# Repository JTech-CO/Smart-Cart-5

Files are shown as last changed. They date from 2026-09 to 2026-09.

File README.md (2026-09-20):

# Smart-Cart-5

[한국어](README-KR.md) · [Assembly viewer](<https://jtech-co.github.io/Smart-Cart-5/>) · [Wiring viewer](<https://jtech-co.github.io/Smart-Cart-5/wiring.html>)

A build-oriented integration model based on a purchased 900 × 600 mm folding platform cart, the supplied V8 component specification, and the original Motor-Bracket/SCMB geometry. Two upright lead-acid batteries sit below the deck, left and right. Rear MY1016Z drives use identical, rigidly rotated SCMB brackets; the controller is a Raspberry Pi 4B 8GB. A handle-mounted NC emergency stop and a separate reset button are included.

**Prototype integration only: dimensional measurement, structural verification and electrical energization remain on hold.** The supplied specification contains unmeasured components. Proposed dimensions and added electrical modules are not presented as purchased-product specifications. The model is not a certified safety system or a production-release drawing.

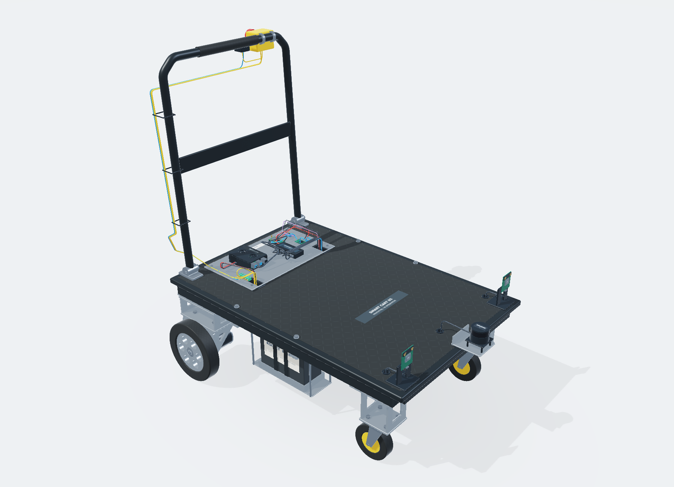
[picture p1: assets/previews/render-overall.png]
Assembly


## Run

Run `start-local.bat` with Python 3 installed, or `./start-local.sh`. Alternatively:

```sh
python -m http.server 8000 --bind 127.0.0.1
```

Serve the repository root. Direct `file://` loading is not supported. The browser runtime is static, with no CDN, account, API key or npm build. The root is suitable for GitHub Pages; no repository has been published by this package.

Drag to orbit, right-drag/Shift-drag to pan, wheel to zoom, double-click to focus. Underside orbit automatically suppresses the ground. WebGL 2 is the primary renderer; a same-mesh depth-buffered Canvas CPU fallback is included for environments without WebGL 2. It is slower and has simplified shading.

## Deliverables

- `cad/Smart-Cart-5.step`: true mm-unit CAD solids, not triangles.
- `cad/Smart-Cart-5.FCStd`: D5-only colored Part::Feature snapshot; no native PartDesign history.
- `cad/Load-Smart-Cart-5.FCMacro`: import the matching BREP files in FreeCAD and fit the view.
- `data/assembly.json`, `geometry.bin`, `connections.csv`: one source for the viewer and 50 routed electrical connections/harnesses.
- `tools/build_release.py`: regenerate geometry, inspect registered cable/solid intersections, and export matching artifacts.

`pip install -r requirements-cad.txt` is needed only for CAD regeneration. Source layout coordinates must be reviewed alongside changed parameters; this is not an automatic routing/structural-optimization system. See the [Korean build guide](docs/BUILD-GUIDE-KR.md) and [QA scope](docs/QA-KR.md).

Native FreeCAD/SolidWorks GUI opening and physical fabrication were not executed. BREP, FCStd payload order and STEP round-trips were checked separately. Browser UI/fallback checks and standalone EGL production-shader renders are distinguished in the QA report.

Original hardware names remain the property of their owners. See [source notices](docs/EVIDENCE-KR.md); this package does not assign a new license to the referenced Motor-Bracket repository.

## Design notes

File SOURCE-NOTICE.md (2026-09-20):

# Source and asset notice

Smart-Cart-5 is a user-requested prototype integration package based on the supplied V8 parts document and JTech-CO's Smart-Cart-4 and Motor-Bracket repositories. See `docs/EVIDENCE-KR.md` for exact scope and source identifiers. The original Motor-Bracket geometry is retained and its engineering-review status remains in effect. This package does not assign a new blanket license to upstream material.

Product names and generated component labels identify referenced hardware; they do not imply manufacturer approval. All preview images are renders of the generated geometry, not photographs of an assembled cart. No proprietary supplier CAD or unavailable product photographs are claimed. The user's original DOCX and font files are not redistributed.

The web runtime does not depend on an external CDN, analytics endpoint, account, API key or live device connection. CAD generation/test dependencies are not required to open the static web viewer through a local HTTP server.

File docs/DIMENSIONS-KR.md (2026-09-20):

# 치수와 근거 등급

단위 mm. 좌표는 +X 전방, +Y 차체 좌측, +Z 위쪽, 바닥 Z=0이다. A=V8 공식자료, B=계열 참고, M=실측 필요, D=이번 배치 제안이다. 같은 부품이라도 PCB 외곽은 A이고 케이스·커넥터·장착 위치는 D/M일 수 있다.

| 항목 | 적용값 | 근거와 한계 |
|---|---|---|
| 카트 상판 | 900×600 | V8 p9-10 구매 옵션 A |
| 상판 상면 높이 / 두께 | 310 / 18 | D/M. 특대형 실측값 아님 |
| 기존 프레임 | 30×30, 벽 2 | D/M. 실제 단면·용접·볼트 접근 미확정 |
| 전륜 | Ø110 TPR | V8 구매 옵션. 폭32·트레일28·장착면142는 D/M |
| 후륜 | Ø200×40, 허브30 | D/M. V8 확정은 Ø17 보어 옵션뿐 |
| 후륜 축 중심 | X=-335, Y=±319 휠 중심, Z=100 | D 통합 배치 |
| 모터 | 길이170, 축Ø17×44, 몸통Ø72 | V8 p12. 기어박스 윤곽·축 어깨·케이블 출구는 M |
| 충돌 자료 | 원본 브라켓 참고 몸통Ø102 | Ø72와 미해결. 어느 쪽도 실측 확정 취급하지 않음 |
| SCMB 단품 | 148×88×130, 주요 판8 | 원본 형상 구성 유지. 새 카트 체결·하중 검증 없음 |
| 모터 홀 X/Z | (-24.7,42.3), (2.1,55), (54.7,2.1), (41.8,-24.6) | 원본 국부 좌표, 거울상으로 바꾸지 않음 |
| 배터리 | 181×77×167, 2개 | V8 p7 A/B. 약5.5kg/개, 단자 위치·입고 변형 M |
| 배터리 배치 | X=-40, Y=±185, 바닥Z84 | D. 두 개 모두 세운 자세 |
| 트레이 최저점 | 약79 | D. 전체 차량 최소 지상고와 같지 않음 |
| 배터리 가로 보강대 | 30×590×10, 2개 | D/M. 원래 차체 실측과 하중 검증 필수 |
| Pi PCB | 85×56 | V8 p24 A |
| Pi + RBP-002 케이스 | 100×75×35 공간예약 | V8 D/M. 실제 케이스·팬·포트 외곽 미확정 |
| BU04 PCB | 46×52, 2개 | V8 A. 지지대·방향·최대높이 M/D |
| BU03 PCB | 35.56×55, 1개 | V8 A. 사용자 소지 외장품, 카트에 붙이지 않음 |
| RPLIDAR C1 | 55.6×55.6×41.3 | V8 p13 A. 홀43×43, M2.5 체결깊이≤4 |
| C1 스캔 높이 | 바닥 기준 367.8 | D 배치 + V8 센서 기준면29.8. 적재물로 후방 가림 가능 |
| ESP32 | PCB54.4×27.9 참고 | V8 B/M. 48.26 길이의 다른 공식 리비전과 혼동 금지 |
| BTS7960 | 보수 공간52×52×43, 2개 | V8 D/B/M. 실제 PCB·방열판·단자 순서 M |
| INA226 | PCB27×20 참고 | V8 B/M. 전류 패드 OPEN, VBUS 접근 핀 M |
| 손잡이 | 상판 위670, 튜브Ø25 | D/M. 작은 카트 이미지의 값을 특대형 확정값으로 전용하지 않음 |
| 12AWG / 18AWG 외경 | 4.4 / 2.6 | V8 범위 내 임시값. 공급품 실제 외경과 허용 굴곡 우선 |

DC/DC, 접촉기, 분배 단자, 퓨즈 하우징, 비상정지 박스, RESET, USB 허브, 레벨 인터페이스, 보강대, 제어 커버는 추가 설계품 또는 공간예약이다. 외형이 보인다는 이유로 특정 판매제품과 일치한다고 해석하면 안 된다.

V8에서 별도 제품사진이나 정확한 도면이 제공되지 않은 부품의 IC·방열판·팬·단자 디테일은 시각 참고 형상이다. PCB 배선 패턴이나 케이스 내부까지 실물을 복제한 것은 아니다. 원본 18kg 시나리오는 이번 카트의 검증된 총중량·적재하중이 아니며 승차를 허용하지 않는다.

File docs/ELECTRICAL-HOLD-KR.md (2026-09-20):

# 통전 보류 조건

서비스 커넥터는 OPEN이다. 렌더링과 솔리드 간섭 검사는 전기 안전 검증이 아니다. 아래 사항이 해결되기 전 모터 구동 전원을 연결하지 않는다. 실제 위험 에너지는 두 납축전지에서 발생하므로 단순히 소프트웨어 PWM을 0으로 만드는 것으로 정비 격리를 대신하지 않는다.

## 공급·보호 소자 선정

V8에는 퓨즈, 접촉기, DC/DC, 비상정지 접점과 USB 허브의 확정 모델이 없다. 본 패키지는 위치와 배선 공간을 추가했을 뿐 재고·구매 가능성과 정격 적합성을 확정한 BOM이 아니다. 배터리 측 두 퓨즈와 좌우 모터·보조전원·코일·계측 분기 퓨즈는 모두 TBD이다. 전선 허용전류, 단자·커넥터 정격, 모터 기동/구속 전류, 온도 및 DC 차단용량에 맞춰 선정해야 한다. USB나 보조 배선 규격을 모터 전류 경로에 적용하지 않는다.

V8의 BTS7960 표기 43A는 지속전류 보증치가 아니다. 구매 모듈의 입력 상한, 충전 조건에서의 배터리 전압, 감속 회생 및 배선 과도전압, 방열판 온도와 연속 운전 온도를 검증한다. 아직 선정되지 않은 TVS·회생 흡수·과전압 보호 소자가 동작한다고 가정하지 않는다. 차체를 귀환 전류 경로로 쓰지 않는다.

Pi4에는 조정된 별도 5.1V 공급이 필요하다. 공식 Pi4 전원은 5.1V 3A이며, 여기서 표시한 6A 이상 DC/DC 공간은 Pi·외부전원 USB 허브·보조부를 함께 고려한 설계 예산이지 선정된 부품 사양이 아니다. 실제 케이블 전압 강하, USB-C 연결 방식, 허브 역급전 방지, 총 센서 소비전류와 리플을 확인한다. V8의 UWB 보드 전원 권고를 모든 포트가 동시에 만족하는지 확인한다.

## 비상정지

E-stop의 NC 접점은 K1 앞의 퓨즈에서 공급받는 코일 회로에 직렬로 둔다. RESET 순간 NO와 K1 보조 NO를 병렬로 하는 자기유지 구성을 제안한다. E-stop 해제만으로 코일이 다시 유지되면 안 된다. 코일 단락·억제 소자·단선·접점 용착·제어기 부팅/리셋·PWM 기본 상태를 확인한다. 회로의 안전 성능 수준이나 정지 카테고리를 인증한 것은 아니다.

코일 억제 부품은 낙하시간에 영향을 주므로 실제 선정과 시험이 필요하다. 이 모델에는 최종 억제 소자가 선정·검증되어 있지 않다. 구동 전원 차단은 제동 장치가 아니다. 관성, 경사면 밀림, 정지거리, 잔류 전압을 실측하고 필요한 제동 방법을 별도로 결정한다.

이 버전의 Pi/DC/DC 분기는 K1 뒤에 있다. 비상정지 시 Pi도 강제 전원 차단된다. 읽기 전용 OS·데이터 보호 또는 별도 로직 전원 계통을 적용하기 전 저장장치의 안전한 종료가 보장되지 않는다. 모델에 없는 UPS나 유지 전원을 있다고 간주하지 않는다.

## 계측과 신호

INA226의 R010 경로는 두 모터의 합산 전류를 흘리는 경로에 넣지 않았다. V8의 ‘20A급 판매모듈 사례’는 모터 피크 적합성 검토가 필요하다고 표시되어 있다. VBUS 감시를 위한 저전류 분기만 제안했고, 구매 모듈에서 VBUS 핀에 접근 가능한지부터 확인해야 한다. 실제 전체 전류 측정은 허용 범위가 맞는 외부 션트·보호·캘리브레이션을 별도로 설계한다.

BTS7960, ESP32와 레벨 인터페이스의 실제 핀 순서·전압 문턱·기본 비활성 상태를 확인한다. CSV의 제어 하네스 항목은 묶음 케이블 경로이다. 개별 GPIO 핀번호까지 검증된 배선표가 아니다. 이 저장소는 로봇 주행 펌웨어나 제어 알고리즘을 구현하지 않는다.

## 충전·정비

2개의 12V 충전기는 외장품이다. 배터리와 직렬 링크를 안전하게 분리·절연한 상태에서 각각 충전하며, 충전기 출력 사이의 절연을 확인하지 않은 병행 연결은 제시하지 않는다. 실제 단자 압착, 러그 볼트, 피복 보호, 퓨즈 홀더 체결과 극성 표시를 확인한다. 최초 시험은 바퀴를 지면에서 띄우고 적절한 전류 제한·전압 계측 환경에서 수행하며, 장착 상태 하중·제동 시험과 분리한다.

출처: 첨부 V8 p3/5/17/19/22-26 및 Raspberry Pi 공식 전원 제품 페이지. https://www.raspberrypi.com/products/type-c-power-supply/

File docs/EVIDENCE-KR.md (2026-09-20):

# 근거와 설계 결정

기준일: 2026-09-21. 이 파일은 구매품의 실측 보고서가 아니라, 받은 자료에서 가져온 값과 이번 통합 모델의 제안을 구분하는 추적표이다.

## 1. 입력 자료

**사용자 제공 V8**: `AI_자율추종_캐리어_Astra_3D_CAD_부품규격서_V8_내용정리본.docx`. 문서의 A/B/M 구분과 품목 1~15 구성을 기준으로 했다. 원본 문서는 이 배포물에 재포함하지 않는다. 아래 페이지 번호는 제공 문서의 렌더된 30페이지 기준이다.

| V8 위치 | 모델에 사용한 근거 | 이번 모델에서 확정하지 않은 것 |
|---|---|---|
| p3~6, BU03/BU04 | PCB 35.56×55 / 46×52, BU04 2개 | 전체 높이, 안테나 방향과 금속 이격 성능, 커넥터/지지대 |
| p7~8, 배터리 | 181×77×167, 2개, 약5.5kg/개 | 입고 변형, 정확한 단자 좌표, 실물 총중량 |
| p9~10, 카트 | 특대형 구매 옵션 900×600, 110mm TPR | 상판 높이·두께, 프레임 단면·용접, 큰 카트의 손잡이·힌지 |
| p11~12, 모터 | MY1016Z 24V250W, 180rpm 옵션, 길이170, 축Ø17×44, V8 몸통Ø72 | 기어박스 외곽·귀 두께·축 어깨·허브 결합·축 허용하중 |
| p13~14, C1 | 55.6×55.6×41.3, 홀43×43, 기준면+29.8 스캔 높이 | 특정 적재 상태의 스캔 가림과 장애물 검출 성능 |
| p15~18, ESP32/드라이버 | ESP32 참고 외곽, BTS7960 보수 공간52×52×43 | 구매 리비전의 핀/단자 순서, 지속전류·방열 |
| p19~21, 충전기/터미널 | 충전기는 외장 사용 가능, 사용하는 단자만 모델링 | 충전기 절연·단자별 전류 정격. 소모품 상자는 탑재하지 않음 |
| p22~23, 케이블 | 12AWG 4~4.5 OD, 18AWG 2.3~2.9 OD 참고, 4×OD 임시 굴곡 기준 | 실제 공급 케이블의 외경·굴곡·단자 압착·허용전류 |
| p24~25, Pi | Pi 4B 8GB, PCB85×56, RBP-002 100×75×35 공간예약 | 실제 케이스 외곽·팬·포트·고정홀 |
| p26~27, INA226 | 참고 PCB27×20, 전류 범위 별도 검토 필요 | 모터 합산 전류 측정 가능 여부. 전류 패드는 OPEN 유지 |
| p28~29, 구동 휠 | Ø17 보어 구매 옵션 | 외경·폭·허브·키홈·고정방식 전부 실측 필요 |

## 2. Smart-Cart-4에서 바꾼 범위

원본: https://github.com/JTech-CO/Smart-Cart-4  
확인한 기본 브랜치 스냅샷: `0d91785fc66699fb12a4c7b55bae2dfbb1adad1c`

원본의 전체 알루미늄 프로파일 구조와 이전 전장 배치를 그대로 축소하지 않았다. V8에 맞춰 기성 플랫폼·보강대·높이 연결대·배터리 트레이로 구조를 새로 구성했다. V8에 없는 전륜 서보/ToF 등의 이전 부품을 자동으로 이월하지 않았다. 앞바퀴는 자유회전 캐스터, 뒤는 좌우 독립 구동이다. 이전 제어 펌웨어나 자율추종 알고리즘을 이 패키지에 이식한 것은 아니다.

렌더러는 새 D5 메시와 Z-up 좌표를 사용한다. 시점이 아래로 내려갈 때 지면을 그리지 않으며, 상판·커버·배선을 독립 제어한다. CPU 호환 경로도 동일한 메시를 사용한다. CAD에는 D4의 숨겨진 과거 형상을 넣지 않는다.

## 3. Motor-Bracket 통합

원본: https://github.com/JTech-CO/Motor-Bracket

- `parameters.json` blob SHA: `81c48461c54e75b0c63525a2e6f43806858f77a3`
- `src/build_cadquery.py` blob SHA: `7b62a49bb4a3ead57460ee48a6d83fc5e8503644`
- `README-KR.md` 및 FCStd 패키징 소스의 구조·한계 설명도 확인했다.

`tools/bracket_geometry.py`는 원본의 솔리드 생성 구조를 재현한다. 외곽, 8mm 주요 판, R10 루트, 큰 경량화 창, Ø60 축 주변 여유, 비대칭 모터 홀과 차체 체결홀을 유지했다. 재생성한 본체 한 개의 질량은 밀도 2.7e-6kg/mm³에서 약0.615083kg이다. 이는 단순 외곽 블록으로 대체한 브라켓이 아니라 실제 관통홀과 창을 가진 BREP 솔리드이다.

반대편에는 동일한 가공품을 Z축으로 180° 회전했다. 홀을 반전한 별도 거울상 부품은 아니다. 원본의 8mm 스페이서와 88mm 축-접촉상면 높이를 보존하고, 카트와 연결하는 높이 보정대는 별도 D/M 부품으로 추가했다.

**자료 충돌:** Motor-Bracket의 모터 참고 외곽은 Ø102, V8 본문은 Ø72이다. 이 모델은 사용자가 이번 작업의 기준으로 지정한 V8의 Ø72를 사용한다. Ø102를 실측값으로 채택하거나, Ø102 대체 외곽까지 간섭 검증했다고 주장하지 않는다. 입고 모터 실측 후 해당 형상과 경로를 다시 검사해야 한다.

원본의 18kg 하중 시나리오, 모터축 허용하중 미확정, 제작 승인 보류는 해소되지 않았다. 배터리 2개만 명목 약11kg이므로 18kg을 이번 카트의 검증된 운행 총중량으로 표시하지 않는다.

## 4. V8에 없는 추가품

24V 계통용 접촉기 K1, 정비용 분리 커넥터, 퓨즈 홀더·퓨즈, 5.1V DC/DC, 분배 단자, 수동 RESET, 외부전원 USB 허브, 제어 인터페이스, 절연 부싱과 보강 부품을 추가 설계했다. 이들은 회로 구성과 물리적 설치 공간을 표시하기 위한 **설계 제안/공간예약**이다. 특정 구매품의 재고, 가격, 외형, 정격과 일치함을 확인한 것은 아니다.

손잡이 비상정지는 사용자 요구에 따른 추가 구성이다. 2개의 납축전지 직렬 전원, 구동/보조 전원 분기와 코일 자기유지 회로를 분리해 표현한다. 단, 이 모델은 안전 등급을 인증한 회로나 개별 PCB 핀까지 확정한 제작 배선도가 아니다. [통전 보류 조건](ELECTRICAL-HOLD-KR.md)을 함께 읽는다.

## 5. 재질과 시각 디테일

금속·고무·도장·배터리 수지·PCB·전선 피복의 색, 금속성, 거칠기, 표면 패턴과 부품 라벨을 사용한다. V8의 미확인 제품사진을 대신 실제 제품사진을 확보했다고 주장하지 않는다. IC 배치·팬 블레이드·케이스 방열부·타이어 트레드 등은 식별과 공간 검토를 위한 시각 참고이다. 실물 제품의 모든 내부 구조를 복제한 것은 아니다.

`docs/source-provenance.json`은 제공 DOCX와 로컬 기준 JSON의 SHA-256을 기록한다. `SHA256SUMS.txt`는 배포 파일 무결성 목록이며 실제 제품의 치수 인증이나 제작 승인을 뜻하지 않는다.

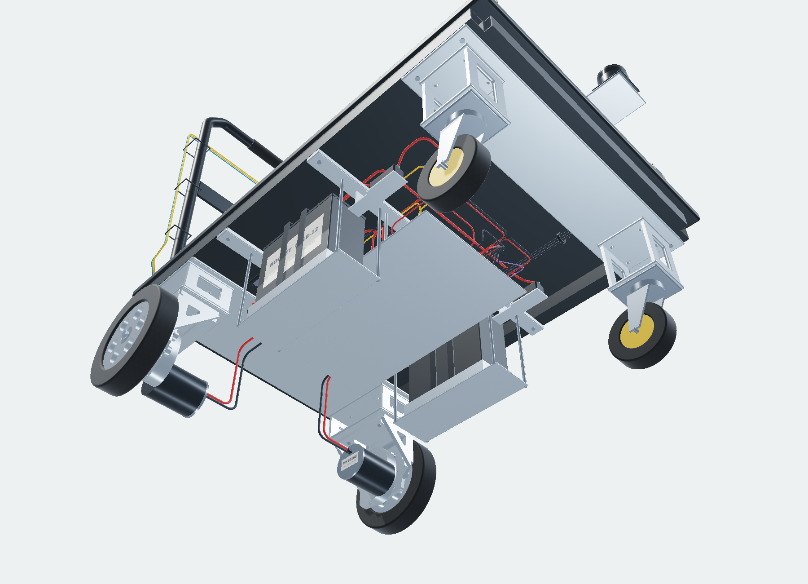
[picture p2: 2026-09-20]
assets/previews/render-underside.png

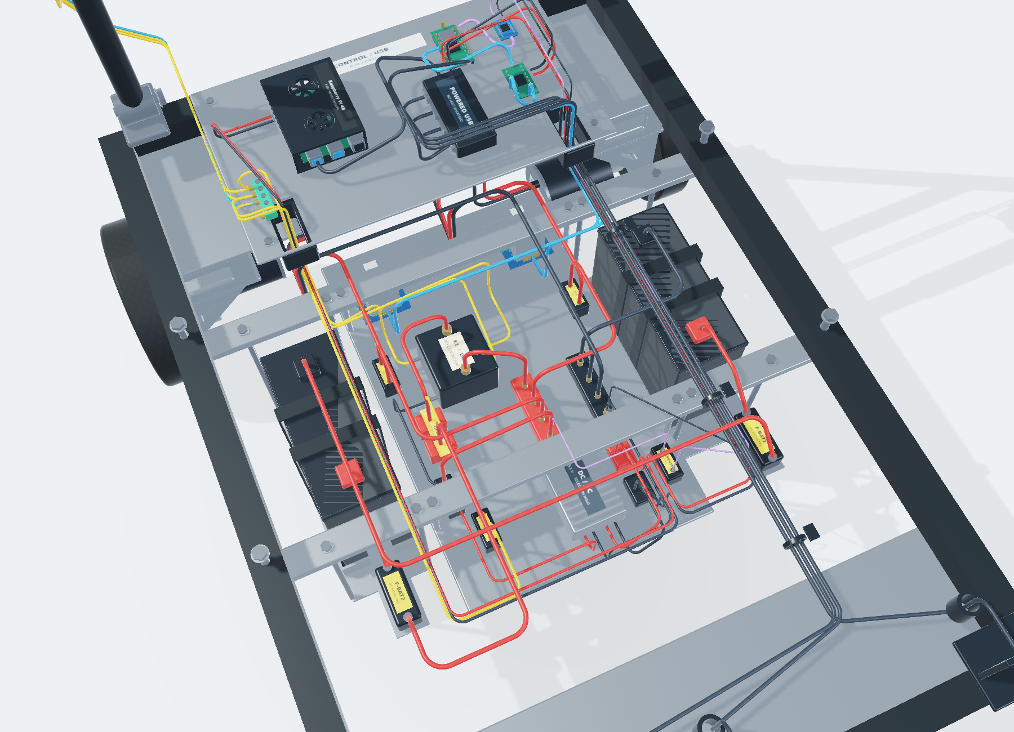
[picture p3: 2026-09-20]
assets/previews/render-power.png

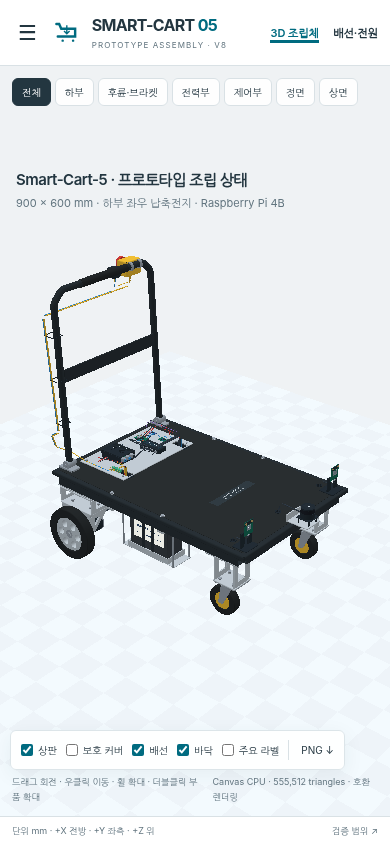
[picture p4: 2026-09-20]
assets/previews/ui-mobile.png

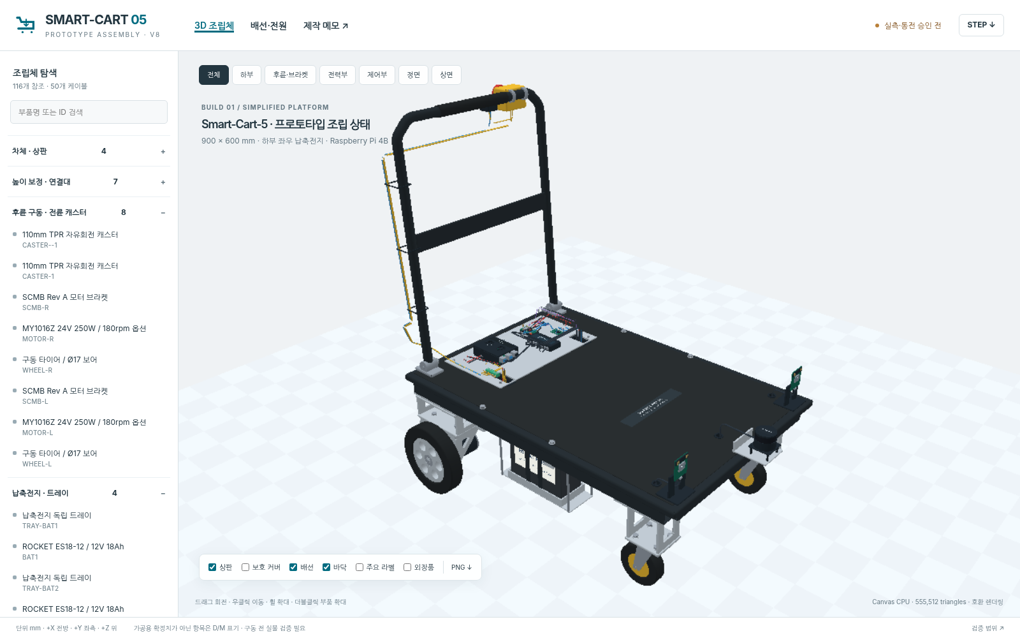
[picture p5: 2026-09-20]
assets/previews/ui-overall.png

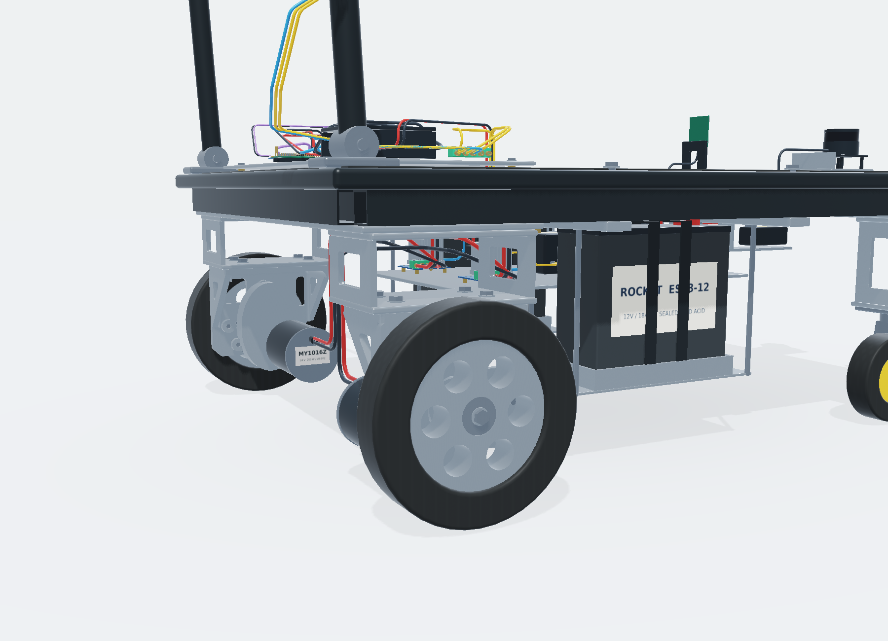
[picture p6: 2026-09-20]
assets/previews/render-drive.png

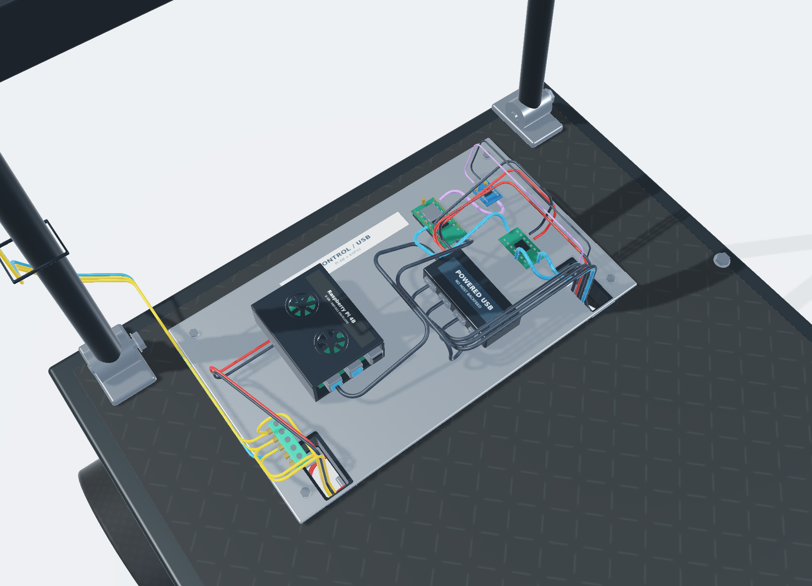
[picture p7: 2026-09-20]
assets/previews/render-controls.png

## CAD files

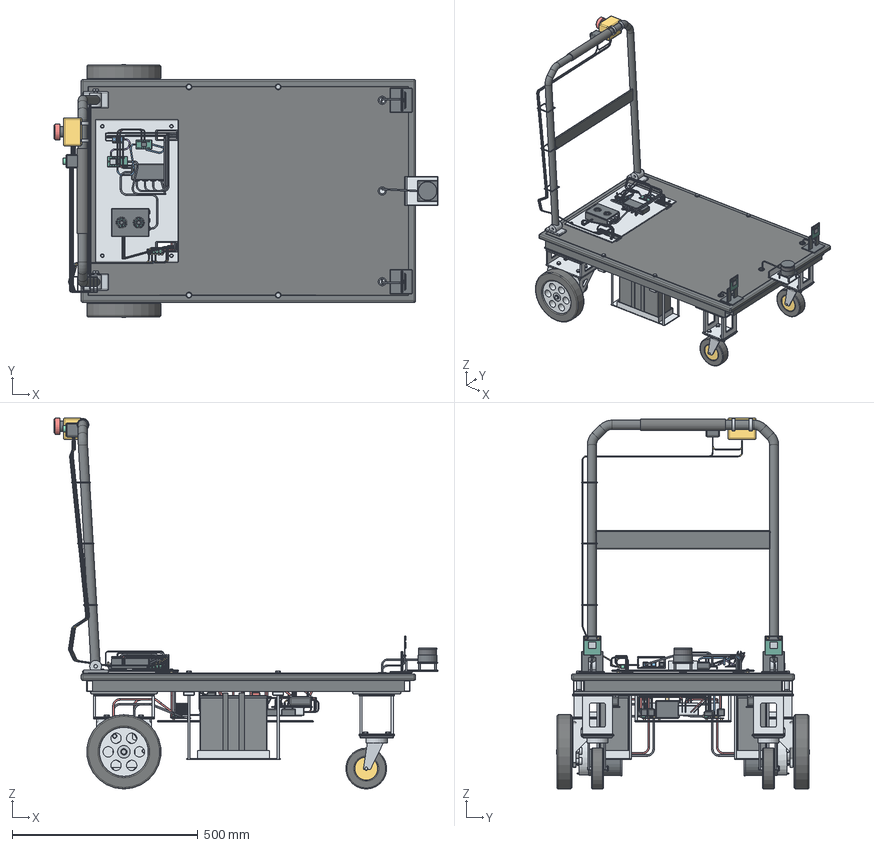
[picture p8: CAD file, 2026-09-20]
cad/Smart-Cart-5.FCStd
1033.0 x 680.4 x 998.0 mm
데스텀 900 × 600 상판 / CART-DECK / paint
미끄럼 방지 매트 / DECK-MAT / deckmat
기존 하부 프레임 대용 단면 / FRAME-LONG / paint
FRAME-END / FRAME-END / paint
프레임 하중 분산판 / REAR-SPREADER / silver
프레임 하중 분산판 / REAR-SPREADER / steel
프레임 하중 분산판 / FRONT-SPREADER / silver
프레임 하중 분산판 / FRONT-SPREADER / steel
보호 부싱을 갖춘 60 × 30 배선홀 / GLAND / black
전면 센서 전용 관통홀 / FRONT-GLAND / black
배터리·전력부 하중 전달 가로 보강대 / BATTERY-CROSS / silver
배터리·전력부 하중 전달 가로 보강대 / BATTERY-CROSS / steel
전륜 높이 보정대 / CASTER-RISER--1 / silver
전륜 높이 보정대 / CASTER-RISER--1 / steel
110mm TPR 자유회전 캐스터 / CASTER--1 / steel
110mm TPR 자유회전 캐스터 / CASTER--1 / rubber
110mm TPR 자유회전 캐스터 / CASTER--1 / yellow
110mm TPR 자유회전 캐스터 / CASTER--1 / silver
전륜 높이 보정대 / CASTER-RISER-1 / silver
전륜 높이 보정대 / CASTER-RISER-1 / steel
110mm TPR 자유회전 캐스터 / CASTER-1 / steel
110mm TPR 자유회전 캐스터 / CASTER-1 / rubber
110mm TPR 자유회전 캐스터 / CASTER-1 / yellow
110mm TPR 자유회전 캐스터 / CASTER-1 / silver
SCMB Rev A 모터 브라켓 / SCMB-R / silver
SCMB Rev A 모터 브라켓 / SCMB-R / steel
후륜 브라켓 높이 연결대 / DRIVE-RISER--1 / silver
후륜 브라켓 높이 연결대 / DRIVE-RISER--1 / steel
MY1016Z 24V 250W / 180rpm 옵션 / MOTOR-R / silver
MY1016Z 24V 250W / 180rpm 옵션 / MOTOR-R / black
MY1016Z 24V 250W / 180rpm 옵션 / MOTOR-R / steel
MY1016Z 24V 250W / 180rpm 옵션 / MOTOR-R / gold
구동 타이어 / Ø17 보어 / WHEEL-R / rubber
구동 타이어 / Ø17 보어 / WHEEL-R / silver
구동 타이어 / Ø17 보어 / WHEEL-R / steel
SCMB Rev A 모터 브라켓 / SCMB-L / silver
SCMB Rev A 모터 브라켓 / SCMB-L / steel
후륜 브라켓 높이 연결대 / DRIVE-RISER-1 / silver
후륜 브라켓 높이 연결대 / DRIVE-RISER-1 / steel
MY1016Z 24V 250W / 180rpm 옵션 / MOTOR-L / silver
MY1016Z 24V 250W / 180rpm 옵션 / MOTOR-L / black
MY1016Z 24V 250W / 180rpm 옵션 / MOTOR-L / steel
MY1016Z 24V 250W / 180rpm 옵션 / MOTOR-L / gold
구동 타이어 / Ø17 보어 / WHEEL-L / rubber
구동 타이어 / Ø17 보어 / WHEEL-L / silver
구동 타이어 / Ø17 보어 / WHEEL-L / steel
납축전지 독립 트레이 / TRAY-BAT1 / silver
납축전지 독립 트레이 / TRAY-BAT1 / rubber
납축전지 독립 트레이 / TRAY-BAT1 / steel
ROCKET ES18-12 / 12V 18Ah / BAT1 / battery
ROCKET ES18-12 / 12V 18Ah / BAT1 / black
ROCKET ES18-12 / 12V 18Ah / BAT1 / steel
ROCKET ES18-12 / 12V 18Ah / BAT1 / red
납축전지 독립 트레이 / TRAY-BAT1 / paint
배터리 단자 근접 퓨즈 / F-BAT1 / silver
배터리 단자 근접 퓨즈 / F-BAT1 / black
배터리 단자 근접 퓨즈 / F-BAT1 / steel
납축전지 독립 트레이 / TRAY-BAT2 / silver
납축전지 독립 트레이 / TRAY-BAT2 / rubber
납축전지 독립 트레이 / TRAY-BAT2 / steel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

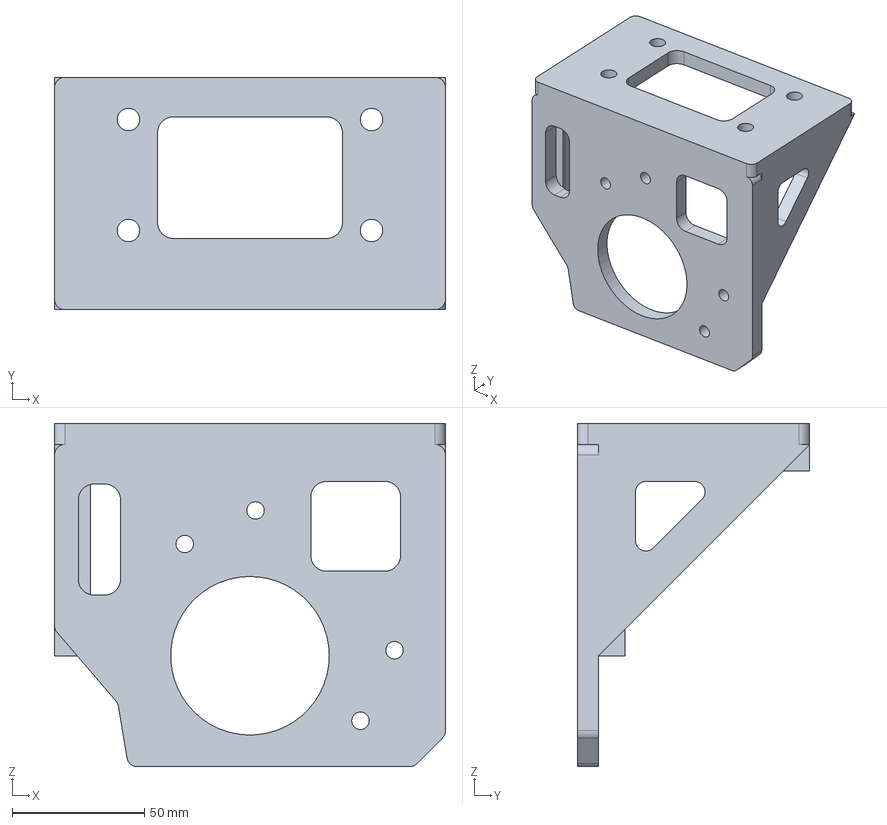
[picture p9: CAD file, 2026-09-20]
cad/SCMB-A01_Bracket.step
148.0 x 88.0 x 130.0 mm

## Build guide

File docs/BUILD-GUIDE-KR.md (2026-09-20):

# Smart-Cart-5 제작 메모

## 먼저 알아둘 범위

이 파일은 실물 부품과 체결·배선 공간을 기준으로 구축한 프로토타입 조립체이다. V8에서 실측을 요구한 수치까지 확정한 제작 승인 도면은 아니다. 구매 전장품의 미확정 정격을 외관상의 라벨이나 블록 크기로 대신하지 않는다. 실제 조립은 치수 확정, 하중 검증, 전장 검증 순서로 진행해야 한다.

## 단순화한 차체

기성 900×600 카트 상판·종방향 프레임·손잡이를 유지한다는 구조이다. 전체 알루미늄 프로파일 외곽 프레임을 새로 만드는 안은 사용하지 않는다. 기존 전륜 110mm TPR 캐스터는 높이 보정대를 사이에 두고 남기며, 후륜은 MY1016Z와 17mm 보어 휠로 교체한다. 후륜에도 원본 SCMB와 별개인 높이 연결대를 사용한다.

배터리는 높이 167mm이므로 원래 카트의 미확정 상판 높이에 억지로 넣지 않았다. 현재 안의 상판 상면은 바닥에서 **310mm**, 배터리 바닥은 **84mm**, 배터리 트레이 최저점은 약 **79mm**이다. 상판 높이 310mm는 구매품 사양이 아니라 제작 제안이다. 휠 지름 200mm, 캐스터 장착면 높이 142mm, 원래 프레임 단면도 미확정이다. 전륜·후륜 높이와 실제 차체 수평을 먼저 맞추어야 한다.

배터리 고정부가 허공이나 얇은 상판에만 매달리지 않도록 두 개의 가로 보강대가 좌우 종프레임 하부에 접촉한다. 배터리 트레이의 연결봉과 중앙 전력 트레이 지지봉은 이 보강대를 통해 지지된다. 보강대와 원래 중공 프레임을 체결하는 위치에는 관통홀과 크러시 슬리브 외형을 추가했다. 그러나 원래 프레임의 실제 단면, 용접부, 내부 접근 가능성, 볼트 체결 길이, 국부 좌굴과 휨 검증은 남아 있다. 표시한 볼트 위치를 그대로 가공 승인 좌표로 사용하면 안 된다.

## 후륜과 모터 브라켓

`Motor-Bracket`의 SCMB 원본 솔리드 구성과 4개 비대칭 장착홀 좌표를 유지했다. 좌우품은 같은 가공품을 Z축으로 180도 회전한 것이며 거울상 가공품이 아니다. 원본의 축 기준 상면 높이 88mm, 외곽 148×88×130mm, 원본 보강 형상과 경량화 창을 유지한다. 원본 질량 약 0.615083kg은 원본 6061 밀도 기준 형상 계산값일 뿐 조립체 허용 하중이 아니다.

V8의 모터 몸통 Ø72와 원본 브라켓의 참고 모터 Ø102는 충돌한다. 본체에는 V8의 Ø72를 사용했고, 이 선택을 실측 해결로 처리하지 않았다. 모터 축의 베어링 허용 반경하중, 휠 오프셋, 키홈, 너트/축 고정 방식과 스페이서 두께 확인이 필수이다. Ø17 보어만 일치한다고 직접 구동 휠 결합이 완성되는 것은 아니다. 원본 브라켓 문서의 18kg 가정도 현재 카트의 검증된 총중량으로 옮기지 않았다.

## 전장 배치

두 납축전지 사이 중앙 트레이에 BTS7960 두 개, K1 접촉기, 서비스 커넥터, 분기 퓨즈, 분배 단자와 DC/DC 공간을 배치했다. 상부 후방의 탈착 플레이트에는 Pi 4B, RBP-002 계열 듀얼팬 케이스의 임시 외곽, 외부전원 USB 허브, ESP32, INA226과 제어 인터페이스 공간을 배치했다. 추가품은 모두 D/M이며 확정 구매 모델이 아니다.

12AWG 전력, 보조전원, USB, 논리 하네스, 비상정지 코일 회로와 전압 감시를 구분했다. 케이블은 선만 그린 것이 아니라 원형 단면을 실제 중심선에 스윕한 솔리드이다. 단자 출발과 도착, 외경, 모델 굴곡반경과 경로 길이는 동일한 연결 데이터에서 나온다. 18AWG를 USB 차동 신호선이나 모든 GPIO 단선의 실제 규격으로 가정하지 않는다.

후방에는 보호 부싱을 갖춘 60×30mm 배선홀 두 곳을, 전면에는 센서 전용 관통홀 세 곳을 추가했다. 전면 USB는 가로 프레임 아래를 뚫고 나가는 대신 프레임 앞의 지정된 홀로 올라온다. BU04 지지대 중앙에는 USB 굴곡 공간을 위한 개구부가 있다. 원래 차체에 없는 가공홀은 D 설계 제안으로 별도 표시했다. 탈착식 제어 커버의 케이블 출구는 실제 케이블과의 교차 위치를 바탕으로 절개했으며 `data/cover-cutouts.json`에서 확인한다.

손잡이 배선은 튜브 내부를 통과시키지 않고 외부 고정 밴드와 힌지 여유 루프를 사용한다. 제공 모델은 손잡이를 펼친 한 자세이며 접힘 전체 운동의 간섭을 검증한 것은 아니다. 접을 때 배선을 잡아당기거나 끼우지 않는지 실물에서 확인한다.

## 비상정지와 충전

손잡이의 래칭 NC 버튼이 K1 코일 경로를 끊고, 별도의 순간 RESET 및 K1 보조 NO 접점으로 수동 자기유지를 구성하는 안이다. E-stop 해제만으로 자동 재시작하지 않는다. 코일 억제 소자, DC 차단 정격, 접점 용착 대응, PWM 기본 차단과 정지거리는 미검증이다. 전원 차단을 즉시 제동 또는 안전 인증으로 간주하지 않는다.

현재 안에서는 Pi 전원도 K1 출력의 DC/DC 분기에서 공급된다. 따라서 비상정지 때 Pi가 강제 전원 차단될 수 있다. 읽기 전용 파일시스템, 상태 저장 정책 또는 별도 비상정지 비차단 로직 전원 계통 중 하나를 실제 설계에서 검토해야 한다. 구현되지 않은 전원 유지 기능을 있다고 가정하지 않는다.

서비스 커넥터는 OPEN 상태로 모델링했다. 두 외장 12V 충전기는 주행체 외장품이며, 배터리와 직렬 링크를 분리하고 충전기의 절연 조건을 확인한 뒤 개별 충전한다. 직렬 연결을 유지한 채 서로 절연되지 않은 충전기 두 개를 연결하는 방식은 제시하지 않는다.

## CAD 열기와 수정

FreeCAD에서는 먼저 `cad/Smart-Cart-5.FCStd`를 연다. 이 파일의 대상은 D5만이며 D4 원형이나 오래된 프로토타입 객체를 포함하지 않는다. 각 Part::Feature에는 실제 BREP 형상이 들어 있다. 문제가 있으면 `cad/Load-Smart-Cart-5.FCMacro`를 실행해 `cad/assembly-manifest.json`을 선택한다. 매크로는 동일 BREP를 새 문서에 넣고 전체 맞춤을 호출한다. 원본을 덮어쓰지 않고 다른 이름으로 저장한다.

SolidWorks 등에서는 `cad/Smart-Cart-5.step`을 mm 단위로 가져온다. 이 STEP은 제조용 솔리드 형식을 사용하지만, 그 사실이 모델의 D/M 치수를 제조 승인한다는 뜻은 아니다. 원본 브라켓 단품은 따로 제공한다. FCStd는 PartDesign/Sketcher의 원래 피처 이력 문서가 아닌 솔리드 스냅샷이다.

재생성 환경에는 `requirements-cad.txt`의 CadQuery를 설치한다.

```sh
python -m pip install -r requirements-cad.txt
python tools/build_release.py
python tools/package_fcstd.py
```

`data/parameters.json`과 `tools/build_model.py`의 관련 배치·배선을 함께 수정한다. JSON에 등장하는 모든 좌표가 전체 배선과 고정부까지 자동으로 재최적화되는 것은 아니다. `build_release.py`는 등록된 주요 고체에 대한 배선 교차나 모델 최소 굴곡 위반이 있으면 내보내기를 중지한다. 실제 치수 변경 후에는 기존 검증 결과를 재사용하지 않는다.

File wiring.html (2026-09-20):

SMART-CART 05WIRING / PROTOTYPE INTEGRATION

서비스 커넥터 OPEN

연결표 CSV ↓

ONE ASSEMBLY / ONE ROUTE DATASET

# 같은 차체, 같은 배선 데이터.

3D 모델의 실제 케이블 중심선을 평면에 투영한 배선도이다. 평면에서 겹치는 선은 높이가 다를 수 있다. 3D의 ‘전력부’ 보기와 함께 확인한다.

통전 전 확인퓨즈·접촉기·전원 모듈 정격과 구매 PCB 핀 배열은 미확정이다. INA226 고전류 단자는 OPEN이며, 이 페이지는 통전 승인 회로도가 아니다.보류 항목 ↗

실제 배치·경로전원·비상정지 구조연결·절단 길이

표시 계통 투영 현재 도면 SVG ↓전선 선택 → 시작·도착·높이·길이

## 전선 또는 부품을 선택한다.

전원선과 배터리 직렬 링크, 손잡이 서비스 루프, 전용 배선홀을 동일한 3D 좌표에서 확인한다.

연결표 CSV ↓가절단 제안은 모델 길이 +15%이다. 구매 길이·실제 압착 여유를 보증하지 않는다.

ID | 시작 → 도착 | 계통 | 외경 | 경로 길이 | 가절단 제안 | 최소 굴곡

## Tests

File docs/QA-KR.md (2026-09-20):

# Smart-Cart-5 검증 범위

검증일: 2026-09-21. 소프트웨어·CAD 형상 검증과 실제 조립/통전 승인을 구분한다. 아래 수치는 가공품 개수나 BOM 구매 수량이 아니다.

## 형상과 데이터

현재 모델은 **116개 선택 참조, 782개 솔리드 구성요소, 209개 재질/참조별 BREP 피처, 50개 케이블·하네스, 555,512개 렌더 삼각형**으로 구성된다. 웹과 CAD는 같은 mm 기준 형상에서 생성한다. 렌더러 내부에서만 m로 변환한다.

| 검사 | 결과 | 근거 |
|---|---|---|
| 209개 BREP 유효성·재읽기 | 통과 | [CAD 컨테이너 검사](cad-container-qa.json) |
| FCStd ZIP CRC·XML·순차 복원 순서 | 통과 | Document.xml → 실제 BREP → GuiDocument.xml 순서 |
| 과거 D4 형상 혼입 | 0개 | 새 D5 피처만 패키징 |
| STEP 재가져오기 | 유효한 768개 솔리드 | [STEP 검사](step-qa.json). 외장품 14개 솔리드 제외 |
| STEP 왕복 체적 상대 오차 | 1.263e-09 | 동일 BREP 집계와 비교 |
| 원본 SCMB 본체 | 0.615083kg/개 | [생성 요약](build-summary.json). 밀도 기반 값, 하중 승인 아님 |
| 데이터·끝단·CSV·메시 일관성 | 별도 자동 검사 | [정적 검사](static-qa.json) |

FCStd의 이전 빈 화면 문제를 피하기 위해 실제 BREP를 올바른 파일 순서로 저장하고 각 피처를 재읽었다. **이는 FreeCAD/SolidWorks 애플리케이션을 직접 실행한 열기 시험이 아니다.** 네이티브 GUI 열기·저장, Sketcher/PartDesign 이력 편집은 미실행이다. STEP 중립 솔리드와 BREP 가져오기 매크로를 대체 경로로 포함한다.

## 배선과 물리 공간

[라우팅 검사](routing-review.json)는 50개 전선의 실제 원형 단면 스윕과 등록된 **116개 장애물 솔리드**를 Open CASCADE로 교차 검사했다. 차체 상판, 주요 프레임, 배터리, 주요 부품, PCB, 보호 커버를 포함한다. 판재 통과부는 실제로 뚫은 홀·부싱·커버 개구부를 사용한다.

교차 체적 0.001mm³ 초과 검출 건수는 0개였다. 모든 케이블이 이 모델에 설정한 임시 최소 굴곡 규칙인 **외경의 4배**를 만족했다. 이 기준은 공급 케이블의 공식 최소 굴곡반경으로 대체해야 한다. 검사에 포함하지 않은 작은 장식 부품·전체 볼트·케이블 상호 이격, 공차, 실제 케이블 쳐짐과 끌림까지 모두 검증했다고 해석하면 안 된다. 펼친 손잡이 기준이며 접힘 운동과 캐스터 전체 동작 영역은 별도 검증 대상이다.

`data/cover-cutouts.json`에는 배선을 피하도록 만든 제어 커버 개구부를 기록했다. 50개 연결 중 USB·논리 하네스는 묶음 경로이다. 개별 구매 PCB의 모든 핀 번호와 전선 가닥 수를 확정한 결선표가 아니다.

## 렌더링

프로덕션 `js/renderer.js`의 **동일 VS/FS 셰이더 문자열**, 동일 `geometry.bin` 및 재질을 Mesa EGL/OpenGL ES 3.2 오프스크린 환경에서 실행했다. 두 셰이더 컴파일, 프로그램 링크, 깊이 프레임버퍼와 5개 시점 렌더를 통과했으며 GL 오류는 0이었다. [실행 기록](offscreen-render.json)

이는 브라우저의 WebGL 전체 초기화·프레젠테이션 검사가 아니라 별도의 실제 GL 실행이다. 첨부 `render-*.png`는 이 경로에서 만든 모델 렌더이며 제품 사진이나 이미지 생성 결과가 아니다. 금속·고무·PCB·피복의 시각적 표현은 제품 실제 재질/공정 인증이 아니다.

## 브라우저와 조작

[브라우저 실행 기록](browser-fixture-qa.json)은 실제 배포 HTML/CSS/JS를 Chromium에 넣고 동일 로컬 JSON/바이너리를 공급하는 fixture 방식의 검사이다. 이 환경에서는 네이티브 브라우저 WebGL 2 대신 동일 메시의 **Canvas CPU 호환 렌더러**를 사용했다. 이 경로의 속도·조명·그림자 품질은 GPU 경로와 다르다.

브라우저 fixture의 42개 검사를 통과했다. 시점 버튼, 실제 마우스 드래그에 따른 하부 진입·바닥 숨김·복원, 방향키, 검색, 픽셀 부품 선택, 선택 부품 확대, 레이어 전환, 모바일 탐색과 시야 보정, 2D 배선 투영·검색·표 선택을 검사한다. PNG와 SVG의 Blob 다운로드는 브라우저 다운로드 경로에서 파일 시그니처/내용을 확인한다. 브라우저별 **네이티브 HTTP URL 탐색이나 file:// 실행, GitHub Pages 실제 게시, localStorage 영속성**을 검증한 것은 아니다. 본 앱은 localStorage 저장 기능을 요구하지 않는다.

## 미실행·미해결

실물 실측과 조립, 토크·전류 실측, 모터축 반경방향 허용하중, 체결·진동·피로, 구조 FEA, 적재/승차, 제동·경사면 정지, 충전·화재·방수·EMI, 전장 정격·안전 성능 인증은 수행하지 않았다. 본체 형상과 전선 경로가 존재한다는 이유로 이 항목을 통과한 것으로 표시하지 않는다. [치수](DIMENSIONS-KR.md)와 [통전 보류 조건](ELECTRICAL-HOLD-KR.md)을 먼저 해소한다.

## 재실행

```sh
python -m pip install -r requirements-cad.txt
python tools/build_release.py
python tools/package_fcstd.py
python tests/static_regression.py
```

`tests/browser_fixture.py`는 Python Playwright와 설치된 Chromium이 추가로 필요하다. `CHROMIUM_PATH`로 실행 파일을 지정할 수 있다. `tools/render_egl.py`는 Linux Mesa EGL/OpenGL ES 및 Pillow가 추가로 필요하다. 렌더와 시험 도구는 웹앱 실행 의존성이 아니다. 형상 수정 뒤 이전 QA JSON만 남겨두지 말고 해당 검사를 다시 실행한다.

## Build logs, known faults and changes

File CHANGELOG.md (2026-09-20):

# Smart-Cart-5 1.0.0

Prototype integration revision; measurement and electrical release remain on hold.

- Replaced the D4 full-extrusion concept with a 900×600 commercial platform, local spreader plates, raised wheel adapters and two suspended battery trays.
- Preserved the Motor-Bracket Rev A BREP construction and asymmetric interface; used a rigid 180-degree rotation for the opposite side rather than a reflected hole pattern.
- Switched the main processor to Raspberry Pi 4B 8GB and reserved the V8 RBP-002 enclosure space.
- Added handle-mounted E-stop and separate manual reset, with visible external handle routes and hinge service loops.
- Rebuilt all 50 cable/harness paths against the new structure; included real grommet holes, cable saddles and removable-cover openings.
- Added same-source 3D/2D physical routing, electrical relationship diagrams and connection length CSV.
- Enabled negative-elevation orbit, automatic ground hiding/restoration and responsive field-of-view compensation.
- Added real solid STEP/FCStd/BREP exports, a FreeCAD import macro, generation code and machine-readable QA reports.
- Corrected coplanar motor-can/end-cap faces, label orientation and shadow self-acne in the final render pass.
- Kept uncertain wheel, motor-body conflict, cart-frame and additional electrical-component dimensions explicit. No firmware, physical load test, energization or manufacturing approval is claimed.

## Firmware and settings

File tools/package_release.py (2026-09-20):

#!/usr/bin/env python3
"""Create and validate a self-contained release ZIP. Standard library only."""
from pathlib import Path
import argparse,hashlib,json,zipfile,shutil,subprocess,sys
ROOT=Path(__file__).resolve().parents[1]
def digest(p):
    h=hashlib.sha256()
    with p.open('rb') as f:
        for block in iter(lambda:f.read(1024*1024),b''):h.update(block)
    return h.hexdigest()
def main():
    ap=argparse.ArgumentParser();ap.add_argument('--output',type=Path,default=ROOT.parent/'Smart-Cart-5-Prototype.zip');args=ap.parse_args();out=args.output.resolve()
    if ROOT in out.parents:raise SystemExit('Write the archive outside the release root.')
    for cache in ROOT.rglob('__pycache__'):shutil.rmtree(cache)
    subprocess.run([sys.executable,str(ROOT/'tests/static_regression.py')],check=True)
    for name in ['static-qa.json','browser-fixture-qa.json','routing-review.json']:
        report=json.loads((ROOT/'docs'/name).read_text())
        if not report.get('passed'):raise SystemExit('Release gate failed: '+name)
    fc=json.loads((ROOT/'docs/cad-container-qa.json').read_text());step=json.loads((ROOT/'docs/step-qa.json').read_text())
    if not(fc['all_brep_roundtrips_valid'] and fc['forward_only_app_payload_order'] and step['valid']):raise SystemExit('CAD gate failed')
    gl=json.loads((ROOT/'docs/offscreen-render.json').read_text())
    if not(gl['program_link'] and all(v['GL_error']==0 for v in gl['views'])):raise SystemExit('Render gate failed')
    manifest=ROOT/'SHA256SUMS.txt'
    files=sorted(p for p in ROOT.rglob('*') if p.is_file() and p!=manifest and '__pycache__' not in p.parts)
    forbidden=[p for p in files if p.suffix.lower() in {'.ttf','.otf','.woff','.woff2'}]
    if forbidden:raise SystemExit('Font files must not be packaged.')
    hashes={str(p.relative_to(ROOT)):digest(p) for p in files}
    manifest.write_text(''.join(h+'  '+n+'\n' for n,h in hashes.items()))
    files.append(manifest);out.parent.mkdir(parents=True,exist_ok=True)
    with zipfile.ZipFile(out,'w',zipfile.ZIP_DEFLATED,compresslevel=6) as z:
        for p in files:z.write(p,str(Path(ROOT.name)/p.relative_to(ROOT)))
    with zipfile.ZipFile(out) as z:
        assert z.testzip() is None
        for name,h in hashes.items():assert hashlib.sha256(z.read(ROOT.name+'/'+name)).hexdigest()==h,name
    result={'file':out.name,'bytes':out.stat().st_size,'sha256':digest(out),'file_count':len(files),'zip_crc_pass':True,'all_manifest_hashes_pass':True,'no_font_files':True,'root':ROOT.name,'native_app_and_physical_limits':'See docs/QA-KR.md; a ZIP release is not an energization approval.'}
    out.with_suffix('.validation.json').write_text(json.dumps(result,indent=2)+'\n');out.with_suffix('.sha256').write_text(result['sha256']+'  '+out.name+'\n')
    print(json.dumps(result,indent=2))
if __name__=='__main__':main()

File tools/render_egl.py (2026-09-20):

#!/usr/bin/env python3
"""Render the production GLSL ES 3 shaders and OCC mesh in an EGL pbuffer.
This verifies the standalone shaders/scene, not a browser WebGL implementation.
Linux Mesa EGL/GLES2, NumPy and Pillow are test-only dependencies.
"""
from pathlib import Path
import os,re,json,math,ctypes as C
import numpy as np
from PIL import Image,ImageDraw,ImageFont
ROOT=Path(__file__).resolve().parents[1];os.environ.setdefault('EGL_PLATFORM','surfaceless')
E=C.CDLL('libEGL.so.1');G=C.CDLL('libGL.so.1');I=C.c_int;U=C.c_uint;F=C.c_float;P=C.c_void_p

def bind(lib,n,ret,args):
 f=getattr(lib,n);f.restype=ret;f.argtypes=args;return f
for n,ret,args in [('eglGetDisplay',P,[P]),('eglInitialize',U,[P,C.POINTER(I),C.POINTER(I)]),('eglBindAPI',U,[U]),('eglChooseConfig',U,[P,C.POINTER(I),C.POINTER(P),I,C.POINTER(I)]),('eglCreatePbufferSurface',P,[P,P,C.POINTER(I)]),('eglCreateContext',P,[P,P,P,C.POINTER(I)]),('eglMakeCurrent',U,[P,P,P,P]),('eglGetError',U,[])]:bind(E,n,ret,args)
dpy=E.eglGetDisplay(None);ma,mi=I(),I();assert E.eglInitialize(dpy,C.byref(ma),C.byref(mi));assert E.eglBindAPI(0x30A0)
attrs=(I*17)(0x3033,1,0x3040,0x40,0x3024,8,0x3023,8,0x3022,8,0x3021,8,0x3025,24,0x3038,0,0)
cfg=P();cnt=I();assert E.eglChooseConfig(dpy,attrs,C.byref(cfg),1,C.byref(cnt)) and cnt.value
W,H=1800,1300;surf=E.eglCreatePbufferSurface(dpy,cfg,(I*5)(0x3057,W,0x3056,H,0x3038));ctx=E.eglCreateContext(dpy,cfg,None,(I*3)(0x3098,3,0x3038));assert surf and ctx and E.eglMakeCurrent(dpy,surf,surf,ctx)
sigs={
 'glGetString':(C.c_char_p,[U]),'glGetError':(U,[]),'glCreateShader':(U,[U]),'glShaderSource':(None,[U,I,C.POINTER(C.c_char_p),C.POINTER(I)]),'glCompileShader':(None,[U]),'glGetShaderiv':(None,[U,U,C.POINTER(I)]),'glGetShaderInfoLog':(None,[U,I,C.POINTER(I),P]),'glCreateProgram':(U,[]),'glAttachShader':(None,[U,U]),'glLinkProgram':(None,[U]),'glGetProgramiv':(None,[U,U,C.POINTER(I)]),'glGetProgramInfoLog':(None,[U,I,C.POINTER(I),P]),'glUseProgram':(None,[U]),'glGetUniformLocation':(I,[U,C.c_char_p]),
 'glUniform1i':(None,[I,I]),'glUniform1f':(None,[I,F]),'glUniform2fv':(None,[I,I,P]),'glUniform3fv':(None,[I,I,P]),'glUniformMatrix4fv':(None,[I,I,U,P]),'glGenVertexArrays':(None,[I,C.POINTER(U)]),'glBindVertexArray':(None,[U]),'glGenBuffers':(None,[I,C.POINTER(U)]),'glBindBuffer':(None,[U,U]),'glBufferData':(None,[U,C.c_ssize_t,P,U]),'glEnableVertexAttribArray':(None,[U]),'glVertexAttribPointer':(None,[U,I,U,U,I,P]),
 'glGenTextures':(None,[I,C.POINTER(U)]),'glBindTexture':(None,[U,U]),'glActiveTexture':(None,[U]),'glTexImage2D':(None,[U,I,I,I,I,I,U,U,P]),'glTexParameteri':(None,[U,U,I]),'glGenerateMipmap':(None,[U]),'glGenFramebuffers':(None,[I,C.POINTER(U)]),'glBindFramebuffer':(None,[U,U]),'glFramebufferTexture2D':(None,[U,U,U,U,I]),'glCheckFramebufferStatus':(U,[U]),'glDrawBuffers':(None,[I,C.POINTER(U)]),'glReadBuffer':(None,[U]),
 'glEnable':(None,[U]),'glDisable':(None,[U]),'glCullFace':(None,[U]),'glViewport':(None,[I,I,I,I]),'glClearColor':(None,[F,F,F,F]),'glClear':(None,[U]),'glDrawArrays':(None,[U,I,I]),'glDepthMask':(None,[U]),'glBlendFunc':(None,[U,U]),'glPolygonOffset':(None,[F,F]),'glReadPixels':(None,[I,I,I,I,U,U,P]),'glFinish':(None,[])}
for n,(rt,args)in sigs.items():bind(G,n,rt,args)
src=(ROOT/'js/renderer.js').read_text();vs=re.search(r'const VS=`(.*?)`;',src,re.S).group(1);fs=re.search(r'const FS=`(.*?)`;',src,re.S).group(1)
def shader(kind,text):
 sh=G.glCreateShader(kind);s=C.c_char_p(text.encode());G.glShaderSource(sh,1,C.byref(s),None);G.glCompileShader(sh);ok=I();G.glGetShaderiv(sh,0x8B81,C.byref(ok))
 if not ok.value:
  buf=C.create_string_buffer(12000);G.glGetShaderInfoLog(sh,12000,None,buf);raise RuntimeError(buf.value.decode())
 return sh
pr=G.glCreateProgram();G.glAttachShader(pr,shader(0x8B31,vs));G.glAttachShader(pr,shader(0x8B30,fs));G.glLinkProgram(pr);ok=I();G.glGetProgramiv(pr,0x8B82,C.byref(ok));assert ok.value;G.glUseProgram(pr)
loc={n:G.glGetUniformLocation(pr,n.encode()) for n in ['vp','lightVP','color','eye','pick','origin','right','up','labelSize','metal','rough','alpha','selected','fade','mode','surface','hasLabel','isFloor','grid','shadowMap','labelMap']}
def u1(n,val):G.glUniform1f(loc[n],float(val))
def ui(n,val):G.glUniform1i(loc[n],int(val))
def uv(n,val):
 a=np.asarray(val,dtype=np.float32);f=G.glUniform3fv if len(a)==3 else G.glUniform2fv;f(loc[n],1,a.ctypes.data)
def um(n,val):
 a=np.ascontiguousarray(val.T,dtype=np.float32);G.glUniformMatrix4fv(loc[n],1,0,a.ctypes.data)
def unit(v):return np.array(v)/np.linalg.norm(v)
def look(e,t):
 z=unit(np.array(e)-t);x=unit(np.cross([0,0,1],z));y=np.cross(z,x);m=np.eye(4);m[:3,:3]=np.array([x,y,z]);m[:3,3]=-m[:3,:3]@np.array(e);return m
def persp(f,a,n,z):
 q=1/math.tan(f/2);return np.array([[q/a,0,0,0],[0,q,0,0],[0,0,(z+n)/(n-z),2*z*n/(n-z)],[0,0,-1,0]])
def ortho(l,r,b,t,n,f):return np.array([[2/(r-l),0,0,-(r+l)/(r-l)],[0,2/(t-b),0,-(t+b)/(t-b)],[0,0,-2/(f-n),-(f+n)/(f-n)],[0,0,0,1]])
def gen(name):
 p=U();getattr(G,name)(1,C.byref(p));return p.value
def make(arr,ref,category,mat):
 ar=np.ascontiguousarray(arr,dtype=np.float32);vao=gen('glGenVertexArrays');G.glBindVertexArray(vao);buf=gen('glGenBuffers');G.glBindBuffer(0x8892,buf);G.glBufferData(0x8892,ar.nbytes,ar.ctypes.data,0x88E4)
 for i,off in [(0,0),(1,12)]:G.glEnableVertexAttribArray(i);G.glVertexAttribPointer(i,3,0x1406,0,24,P(off))
 return {'vao':vao,'count':len(ar),'ref':ref,'category':category,'mat':mat}
D=json.loads((ROOT/'data/assembly.json').read_text());raw=np.fromfile(ROOT/'data/geometry.bin',dtype=np.float32).reshape(-1,6);items=[];decals=[]
for q in D['geometry']:items.append(make(raw[q['offset']//24:q['offset']//24+q['count']],q['ref'],q['category'],D['materials'][q['material']]))
floor=make(np.array([[-8,-8,-.004,0,0,1],[8,-8,-.004,0,0,1],[8,8,-.004,0,0,1],[-8,-8,-.004,0,0,1],[8,8,-.004,0,0,1],[-8,8,-.004,0,0,1]]),'__floor','ground',{'color':'#e5e9eb','metal':0,'rough':1})
for d in D['decals']:
 center=np.array(d['center'])/1000;r=np.array(d['right'])*d['size'][0]/2000;u=np.array(d['up'])*d['size'][1]/2000;n=unit(np.cross(d['right'],d['up']));p=[center-r-u,center+r-u,center+r+u,center-r+u];arr=np.array([np.r_[p[i],n] for i in [0,1,2,0,2,3]])
 item=make(arr,d['ref'],next(c['category'] for c in D['components'] if c['id']==d['ref']),{'color':'#ffffff','metal':0,'rough':.63});item['label']=d
 w=768;h=max(128,round(w*d['size'][1]/d['size'][0]));im=Image.new('RGBA',(w,h),d['bg']);dr=ImageDraw.Draw(im)
 for text,yy,font,cap in [(d['title'],h*.37,'DejaVuSans-Bold.ttf',.31),(d['sub'],h*.72,'DejaVuSans.ttf',.18)]:
  ff=ImageFont.truetype('/usr/share/fonts/truetype/dejavu/'+font,max(8,int(min(h*cap,w/(len(text)*.62+2)))));dr.text((w/2,yy),text,font=ff,fill=d['ink'],anchor='mm')
 image=np.asarray(im).copy();tex=gen('glGenTextures');G.glBindTexture(0x0DE1,tex);G.glTexImage2D(0x0DE1,0,0x1908,w,h,0,0x1908,0x1401,image.ctypes.data);G.glGenerateMipmap(0x0DE1)
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
